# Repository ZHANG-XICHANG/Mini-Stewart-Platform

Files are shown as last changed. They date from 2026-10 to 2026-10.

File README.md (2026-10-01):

# 小型六自由度 Stewart 平台｜ESP32-C6 控制與 Python 上位機

**專案名稱：Mini-Stewart-Platform**

以 Python 上位機設定平台位置與姿態，由 ESP32-C6 計算逆運動學，再透過 PCA9685 控制六組伺服馬達。本專案涵蓋小型化機構設計、控制系統、上位機介面與實機測試。

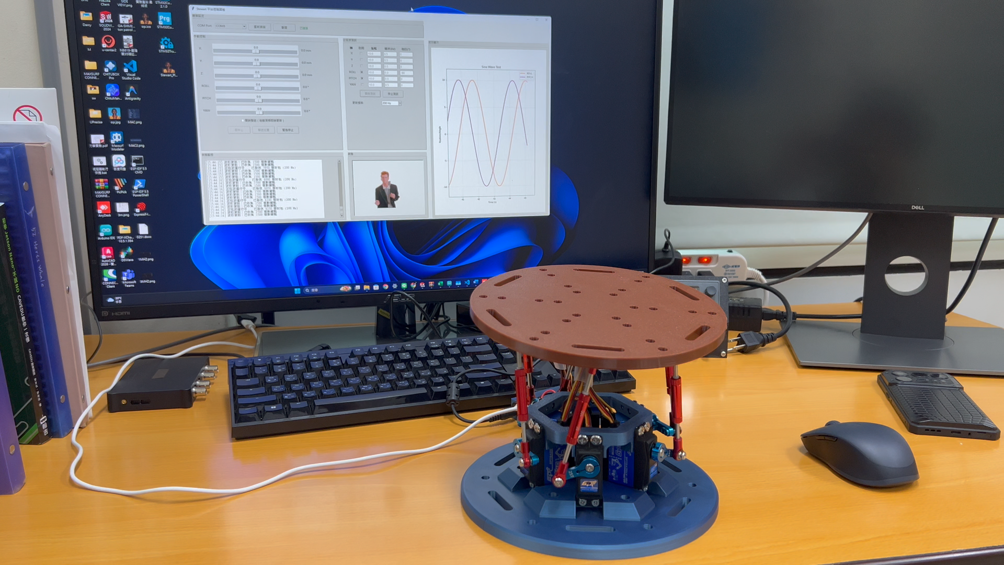
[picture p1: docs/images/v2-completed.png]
二代平台與上位機


**目前狀態：已完成實體組裝與運行測試。** 下方照片與影片展示平台實作及測試成果，本專案提供上位機程式、ESP32 韌體與機構模型，供學習與實作參考。

## 運行展示

- [二代運行影片（MP4）](docs/videos/v2-demo.mp4)
- [初代運行影片（MP4）](docs/videos/v1-demo.mp4)

影片提供 MP4 格式，可播放或下載。

## 開發歷程與個人貢獻

| 初代實機 | 二代實機 |
| --- | --- |
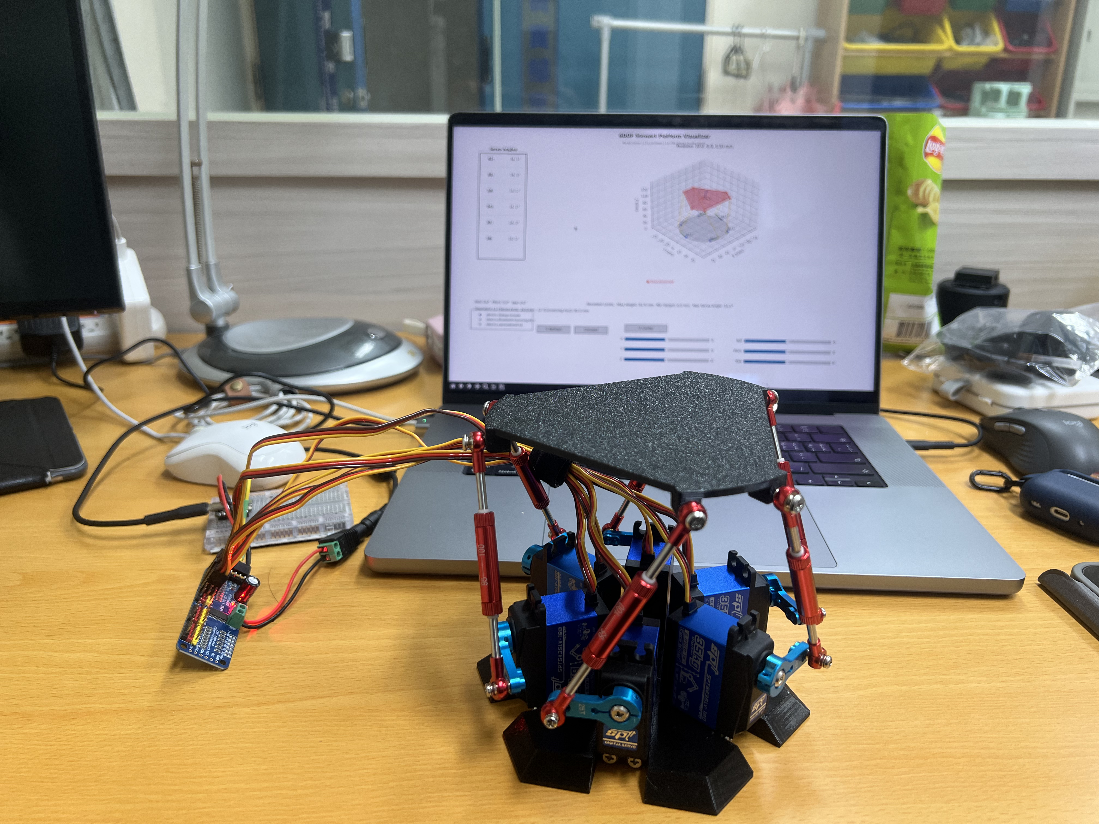
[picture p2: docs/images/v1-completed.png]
初代
|  | 二代 |

- **機構調整**：縮小平台機構，提供 STL、STEP 與 SolidWorks 設計檔。
- **控制系統**：ESP32／PCA9685 控制實作，後續版本將逆運動學移至 ESP32。
- **上位機修改**：提供六軸手動操作、各軸正弦波設定與命令波形顯示。
- **組裝與測試**：完成實體組裝及運動、負載測試；詳細測試條件與量測數據待補充。

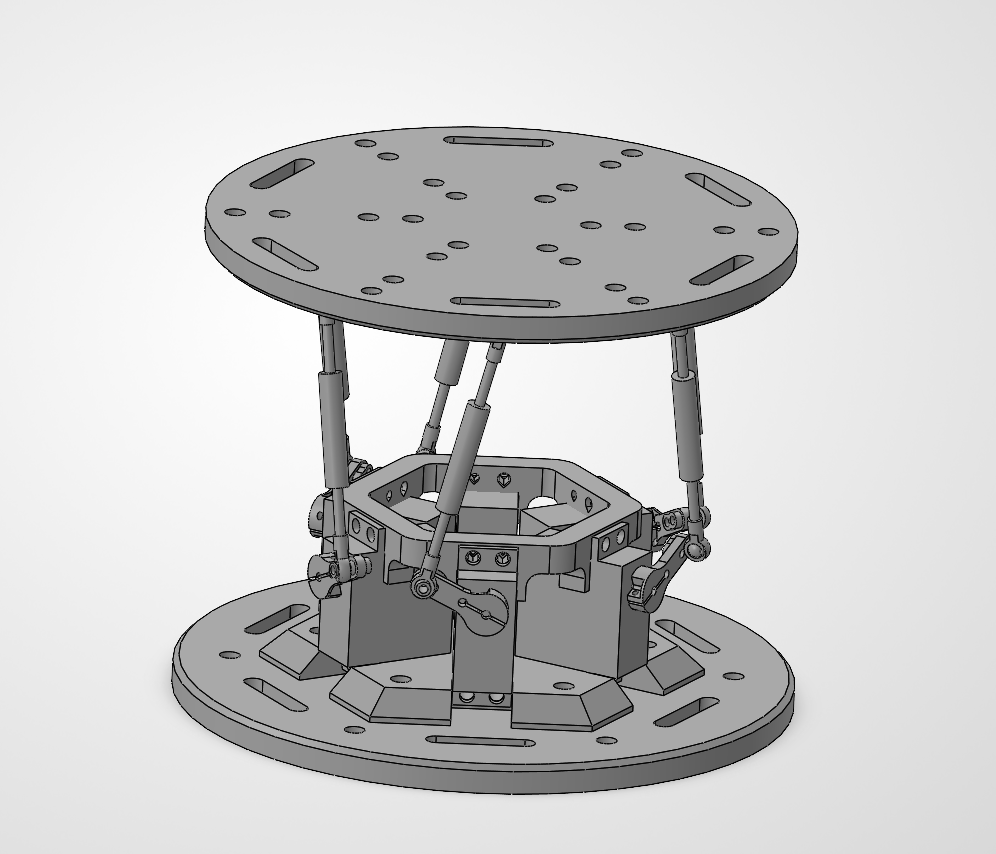
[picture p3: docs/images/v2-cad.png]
二代模型


### 負載測試紀錄

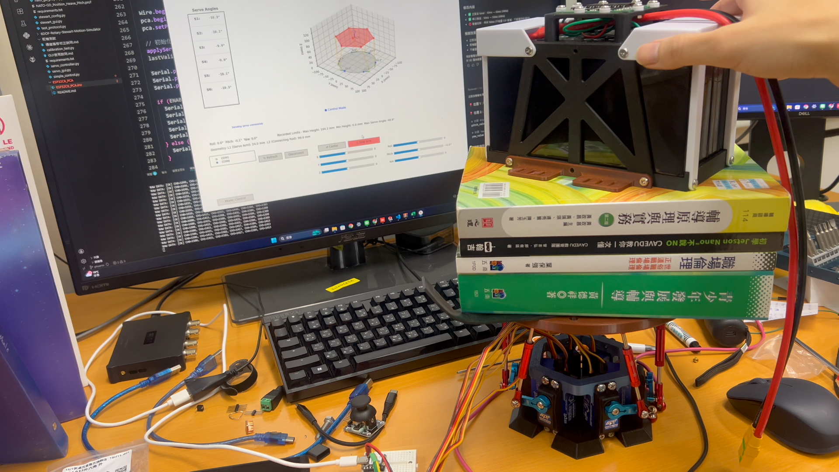
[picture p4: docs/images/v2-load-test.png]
負載測試


此照片記錄放置負載的測試情境。負載重量、持續時間、運動幅度及定位誤差尚未記錄於本專案，因此不據此宣稱最大承載量。另見 [運行照片](docs/images/v2-running.png)。

## 使用入口與目錄

本專案包含所需的上位機程式、ESP32 韌體與相依套件清單，可獨立安裝使用。

日常操作請執行根目錄的 `stewart_control_gui.py`，搭配 `firmware/ESP32C6_PCA/` 韌體。

```text
Mini-Stewart-Platform/
├── stewart_control_gui.py        # 主版本上位機
├── requirements.txt             # Python 相依套件
├── firmware/ESP32C6_PCA/
│   ├── ESP32C6_PCA.ino           # 主版本韌體
│   └── stewart_kinematics.h      # ESP32 逆運動學與幾何參數
├── GIF/Logo.gif                  # 介面標誌
├── docs/images/                  # 實機與模型照片
├── docs/videos/                  # 示範 MP4
├── models/                       # STL、STEP、SolidWorks
├── legacy/binary_pca9685/        # 舊版與二進位相容介面
├── README.md
├── LICENSE
└── .gitignore
```

主版本使用根目錄的上位機與 `firmware/`；`legacy/` 提供舊版程式作為參考。

## 主版本：上位機姿態命令 → ESP32 逆運動學

```mermaid
flowchart TD
    A[上位機：X / Y / Z / Roll / Pitch / Yaw] --> B[USB 串列：460800 baud]
    B --> C[ESP32：座標轉換與逆運動學]
    C --> D[六組馬達角度與 PWM 映射]
    D --> E[PCA9685 驅動平台]
```

| 檔案 | 用途 |
| --- | --- |
| [stewart_control_gui.py](stewart_control_gui.py) | 新版 Python 上位機，傳送姿態 |
| [ESP32C6_PCA.ino](firmware/ESP32C6_PCA/ESP32C6_PCA.ino) | 接收姿態、驅動 PCA9685 |
| [stewart_kinematics.h](firmware/ESP32C6_PCA/stewart_kinematics.h) | ESP32 端幾何參數與逆運動學；須與 ino 放在同一資料夾 |

上位機負責輸入姿態與產生測試命令；ESP32 負責逆運動學與伺服輸出。測試範圍見 [測試與驗證](docs/VALIDATION.md)。

### 安裝上位機

在專案根目錄開啟 PowerShell：

```powershell
python -m venv .venv
.\.venv\Scripts\python.exe -m pip install -r requirements.txt
.\.venv\Scripts\python.exe stewart_control_gui.py
```

需具備 Tkinter 圖形環境。`Pillow` 用於圖片；`matplotlib` 用於波形顯示；`pyserial` 用於串列通訊。`numpy` 亦供保留的舊版視覺化使用。套件版本尚未鎖定。

選擇 ESP32 的 COM 埠並連線，同一埠勿同時由 Arduino 串列監控視窗占用。`GIF/Logo.gif` 用於介面標誌；可在 `GIF/` 放入其他 GIF 作為選用動畫。缺少 GIF 時程式仍可執行。

### 燒錄與硬體設定

1. 在 Arduino IDE 安裝支援實際 ESP32-C6 開發板的 Espressif ESP32 套件。
2. 安裝 `Adafruit PWM Servo Driver Library` 及其相依套件（包含 Adafruit BusIO）。
3. 開啟 `firmware/ESP32C6_PCA/ESP32C6_PCA.ino`；同目錄必須包含 `stewart_kinematics.h`。
4. 核對下列參數與實際機構後，再編譯及上傳。

| 項目 | 主版本程式設定 |
| --- | --- |
| SDA / SCL | GPIO22 / GPIO23 |
| PCA9685 位址 / 通道 | `0x40` / CH0～CH5 |
| 串列速率 | 460800 baud |
| 伺服 PWM 頻率 | **330 Hz**，須符合實際伺服規格 |
| 姿態單位 | 平移 mm、旋轉 degree |
| 底座／平台半徑 | 68 / 68 mm |
| 搖臂／連桿長度 | 24 / 99 mm |
| 中立平台高度 | **96.04 mm** |
| 通道反轉 | CH0、CH2、CH4 |
| 通道偏移 | 80、100、100、0、100、50 µs |
| 通訊逾時 | 1 秒未收到有效姿態，觸發韌體回中位處理 |

伺服電源依規格接 PCA9685 V+，ESP32 與 PCA9685 共地。邏輯 VCC 與 I2C 上拉應配合 ESP32 的 3.3 V 邏輯。韌體包含 PCA 輸出校正，數值針對原實機，不能直接當作其他硬體的量測結果。

### 通訊配對

主版本格式（每包以換行結束）：

```text
$P,x,y,z,roll,pitch,yaw,checksum
```

上位機將數值格式化為小數兩位；checksum 為各值乘 10 後逐項截斷為整數、加總再取低 8 位。`$V,0` 關閉詳細回應、`$V,1` 開啟。韌體使用單精度浮點，上位機使用 Python 浮點，校驗在小數邊界仍需實測確認。

GUI 波形顯示的是命令值，並非感測器量測的平台實際姿態。原介面「緊急停止」的程式行為為停止測試並送出回中心命令，不是切斷馬達電源。手動送出單一命令後若未持續更新，韌體可能於 1 秒後回中位。

## 舊版與相容版

| 版本 | 上位機入口（相對專案根目錄） | 配對韌體 | 通訊格式 |
| --- | --- | --- | --- |
| 主版本 | `stewart_control_gui.py` | `firmware/ESP32C6_PCA/ESP32C6_PCA.ino` | 460800 baud、`$P` 姿態封包 |
| 舊版／相容版 | `legacy/binary_pca9685/6dof_visualizer.py` 或同目錄的 `stewart_control_gui.py` | 該目錄下的 `esp32c6_pca9685_receiver/esp32c6_pca9685_receiver.ino` | 115200 baud、12-byte 角度封包 |

兩個目錄中的上位機使用不同協定，請依表格搭配韌體。

[legacy/binary_pca9685](legacy/binary_pca9685/README.md) 提供 3D 視覺化與 PC 逆運動學相容介面，使用 **115200 baud、12-byte 角度封包**，須搭配該目錄自己的接收器。不要與主版本韌體混用。

## 3D 模型

見 [模型說明](models/README.md)：

- [STL](models/stl/)：列印零件。
- [STEP](models/step/)：組合件交換格式。
- [SolidWorks](models/solidworks/)：組合件與原生零件檔。

開啟 SolidWorks 組合件時請保留零件檔的相對位置；列印前請核對尺寸、配合間隙與材料設定。

## 測試與驗證

實機展示、軟體測試範圍及重現方式見 [測試與驗證](docs/VALIDATION.md)。使用原始碼的安裝方式請參考上方步驟。

## AI 協作說明

本專案使用 OpenAI Codex 協助文件撰寫、程式檢查與部分程式開發。

機構縮小、硬體組裝與實機測試由專案作者完成。實機照片與影片為實際成果紀錄，並非 AI 生成。AI 執行的軟體檢查不等同於硬體驗證，各項測試範圍見 [測試與驗證](docs/VALIDATION.md)。

## 來源與授權

本專案基於 [knaufinator/6DOF-Rotary-Stewart-Motion-Simulator](https://github.com/knaufinator/6DOF-Rotary-Stewart-Motion-Simulator) 進行小型化與控制系統實作，保留原有 [LICENSE](LICENSE) 與 Chris Knauf 署名。

數學推導可參考 Robert Eisele（2019）的 [Inverse Kinematics of a Stewart Platform](https://raw.org/research/inverse-kinematics-of-a-stewart-platform/)。

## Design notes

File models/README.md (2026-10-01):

# 3D 模型

| 目錄 | 內容 | 用途 |
| --- | --- | --- |
| `stl/` | 大平台、底座、控制盒、緊箍，共四個 STL | 匯入切片軟體製作零件 |
| `step/` | `組合件1.STEP` | 在支援 STEP 的 CAD 軟體檢視組合模型 |
| `solidworks/` | SLDASM 組合件與 SLDPRT 零件 | 編輯原生設計 |

開啟 `solidworks/組合件1.SLDASM` 時，請保留各零件的檔名與相對位置，以便解析組合件引用。列印前依使用的伺服、連桿與緊固件確認尺寸單位、配合間隙、列印方向及材料。

檔案格式與內容清單不代表所有 CAD 軟體或印表機皆已測試相容。

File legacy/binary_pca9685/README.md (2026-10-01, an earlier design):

# 舊版二進位控制路徑

此目錄的兩個 PC 介面都搭配 `esp32c6_pca9685_receiver/esp32c6_pca9685_receiver.ino`，使用 115200 baud、12-byte 大端序角度封包。逆運動學在電腦執行。

從此目錄啟動 `6dof_visualizer.py`（3D 視覺化）或 `stewart_control_gui.py`（二進位相容面板），一次只使用一個串列連線。先安裝根目錄的 requirements.txt。

- `stewart_kinematics.py`：從原視覺化抽出的共用計算，三個數學方法內容保持一致。
- `stewart_config.py`：舊版幾何，高度 91.92 mm。
- `pca9685_transport.py`：相容面板使用；拒絕不可達或非有限姿態，只重送最新目標，最多約 50 Hz。
- 接收器：PWM 50 Hz，SDA22／SCL23，通道 0～5，CH0、2、4 反轉。

與主版本的 460800 baud `$P` 協定、330 Hz PWM、96.04 mm 平台高度不同。相容面板尚未實機驗證。舊接收器無封包標頭或校驗碼；接收器的 DEBUG 資料不是實際姿態量測。

## 軟體測試

在本目錄執行：

```powershell
python -m unittest discover -s tests -v
```

測試使用假串列埠，不會驅動硬體。

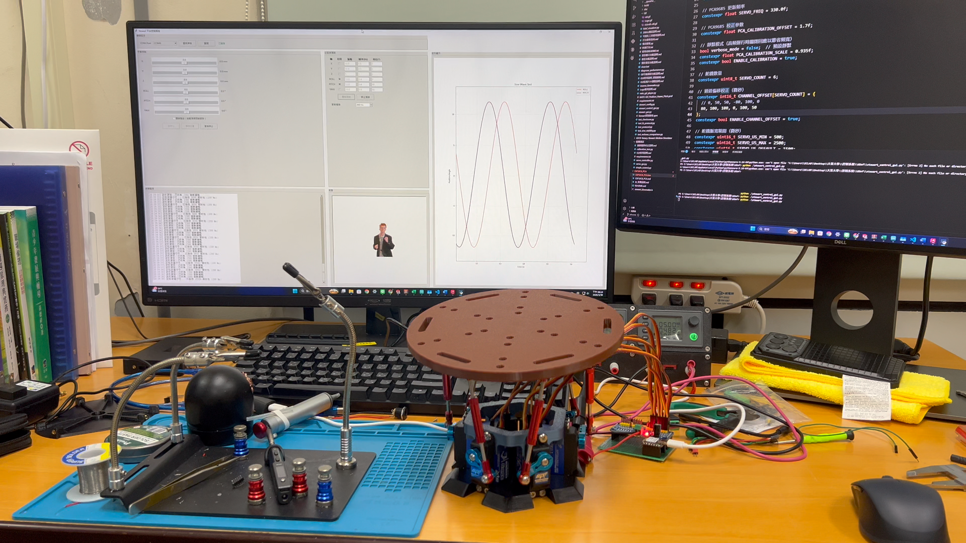
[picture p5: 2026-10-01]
docs/images/v2-running.png

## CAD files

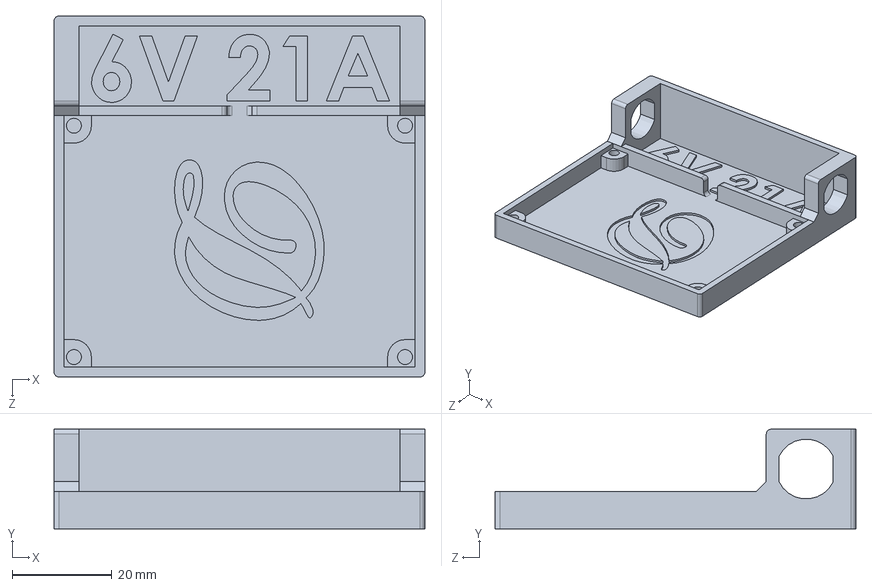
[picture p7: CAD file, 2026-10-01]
models/solidworks/控制盒.SLDPRT
74.4 x 20.0 x 72.4 mm

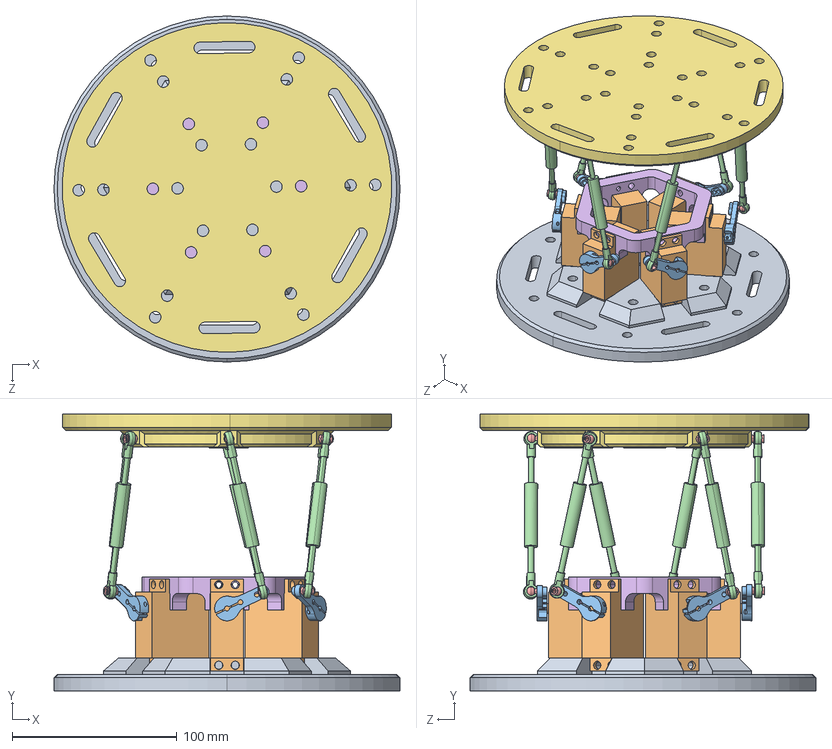
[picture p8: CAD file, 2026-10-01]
models/step/組合件1.STEP
210.0 x 168.0 x 210.0 mm
底座
舵機 x 6
搖臂 x 6
連桿 x 6
球頭 x 12
緊箍
大平台

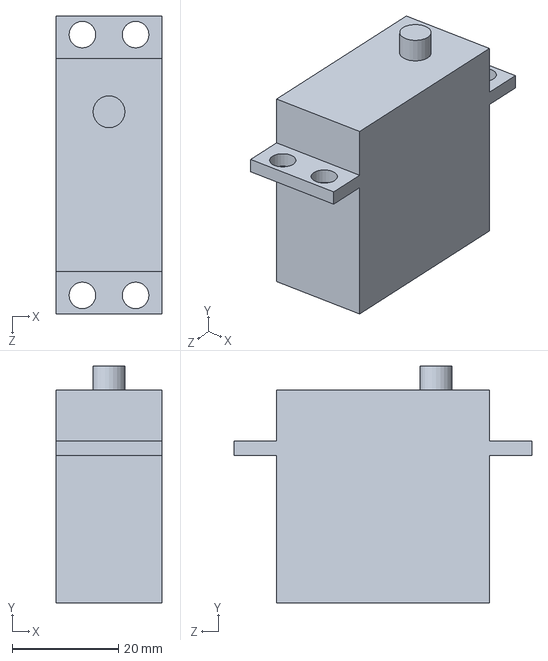
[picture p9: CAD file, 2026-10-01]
models/solidworks/舵機.SLDPRT
20.0 x 44.5 x 56.0 mm

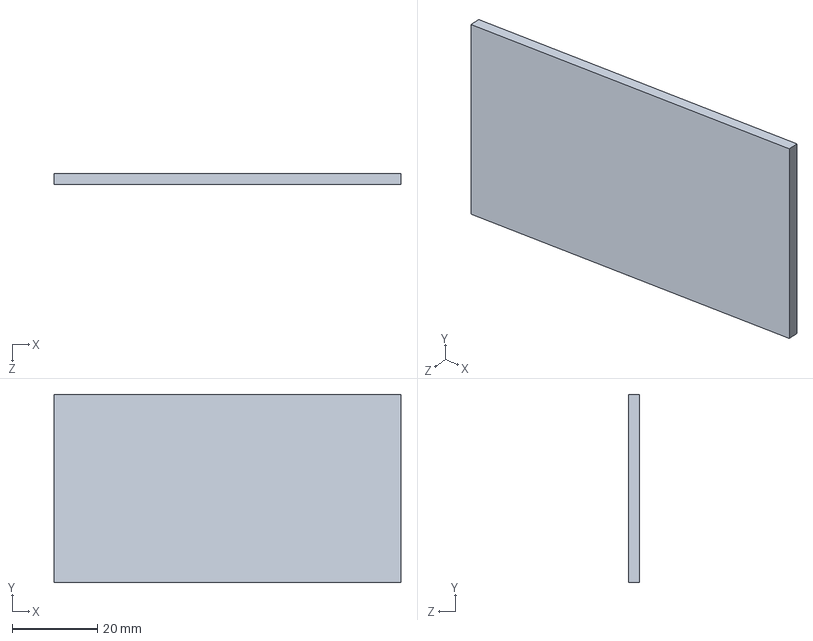
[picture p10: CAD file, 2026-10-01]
models/solidworks/零件9.SLDPRT
81.6 x 44.2 x 2.54 mm

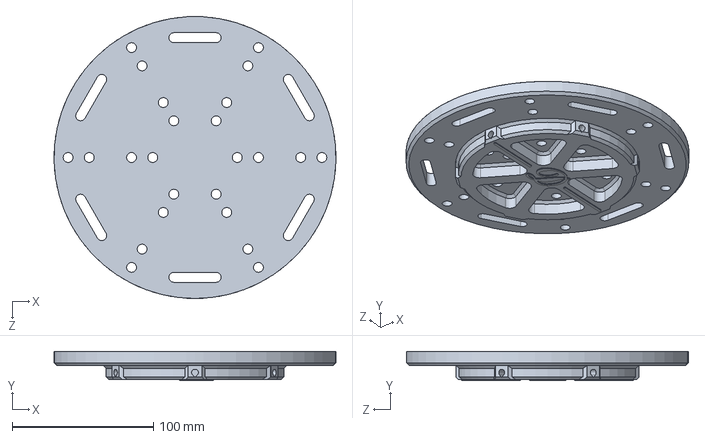
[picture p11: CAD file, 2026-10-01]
models/solidworks/大平台.SLDPRT
199.9 x 20.6 x 200.0 mm

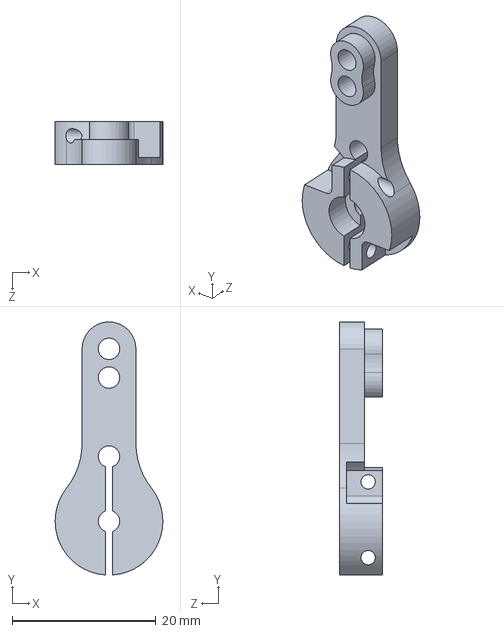
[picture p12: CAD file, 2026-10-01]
models/solidworks/搖臂.SLDPRT
15.0 x 35.2 x 6.00 mm

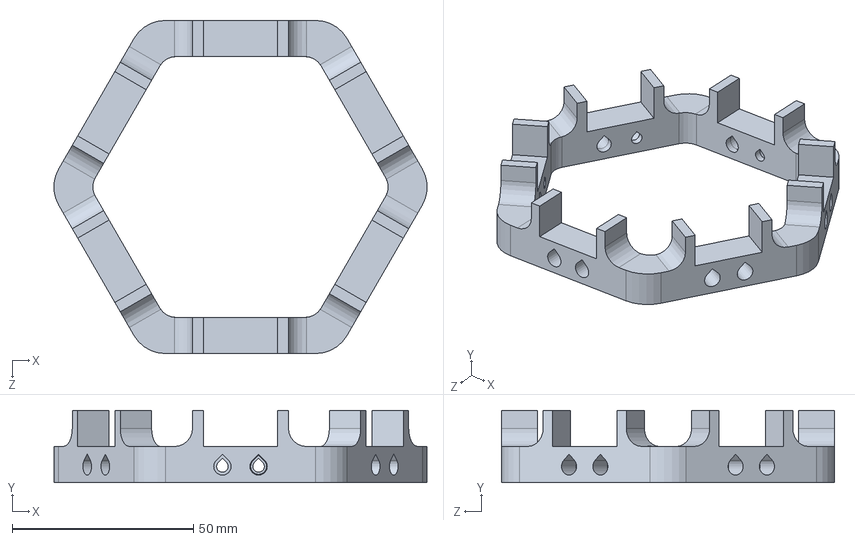
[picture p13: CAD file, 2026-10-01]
models/solidworks/緊箍.SLDPRT
103.0 x 20.0 x 92.0 mm

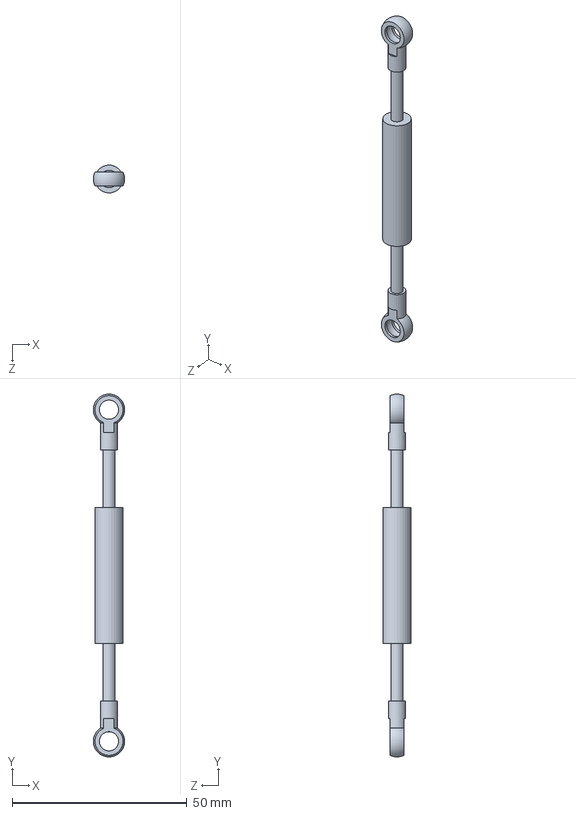
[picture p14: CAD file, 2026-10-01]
models/solidworks/連桿.SLDPRT
8.98 x 104.0 x 7.99 mm

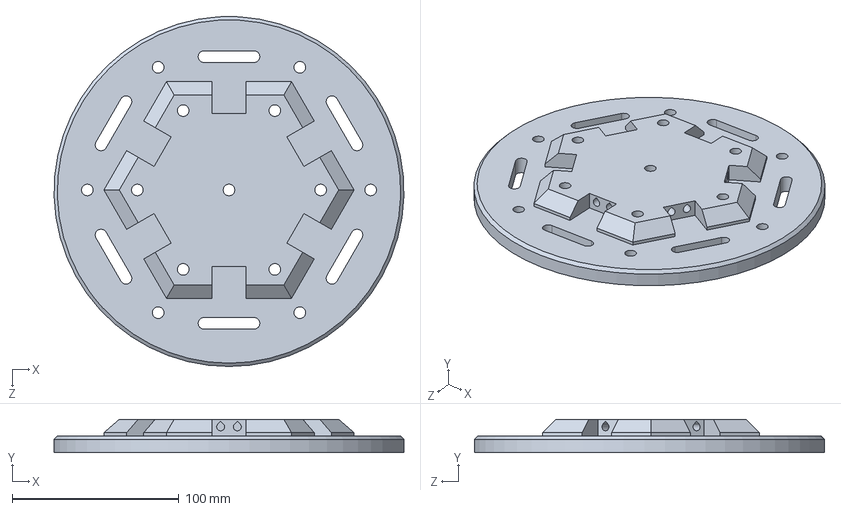
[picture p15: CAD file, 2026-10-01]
models/solidworks/底座.SLDPRT
209.9 x 20.0 x 210.0 mm

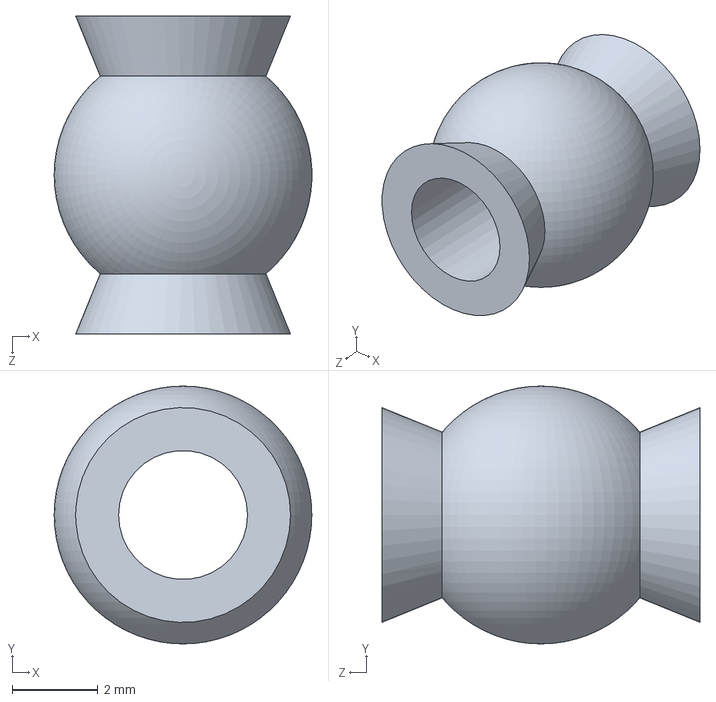
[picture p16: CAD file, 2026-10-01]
models/solidworks/球頭.SLDPRT
6.00 x 6.00 x 7.40 mm

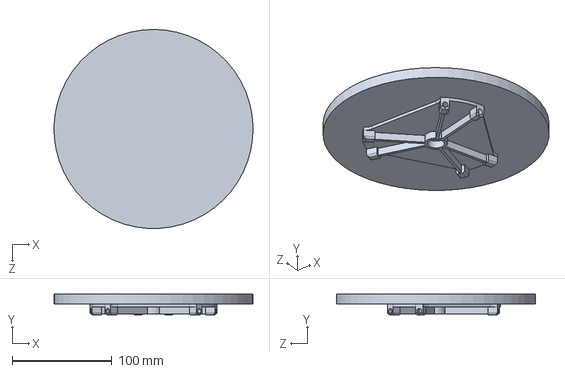
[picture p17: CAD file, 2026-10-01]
models/solidworks/平台.SLDPRT
199.9 x 21.0 x 200.0 mm

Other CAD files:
models/solidworks/組合件1.SLDASM
models/stl/大平台.STL
models/stl/底座.STL
models/stl/控制盒.STL
models/stl/緊箍.STL

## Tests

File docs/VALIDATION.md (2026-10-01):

# 測試與驗證

## 主版本實機展示

平台已完成實體組裝與運行測試，相關紀錄：

- [初代運行影片](videos/v1-demo.mp4)
- [二代運行影片](videos/v2-demo.mp4)
- [負載測試照片](images/v2-load-test.png)

上述資料展示系統運行情形；負載重量、測試時間、姿態誤差與最大工作範圍的量測數據尚未收錄，不能從展示影片推定其定量性能。

## 主版本軟體檢查

- 上位機與韌體的 460800 baud、`$P` 六軸順序、degree 旋轉單位、換行分隔及 `$V,0` 命令已經程式碼對照確認。
- 上位機的隱藏 Tk 視窗初始化檢查通過。
- 軟體檢查未包含 ESP32 編譯、燒錄及硬體串列收發測試；實機展示與軟體檢查的範圍不同。

## 舊版二進位相容面板

以下自動測試針對 `legacy/binary_pca9685`，不代表主版本韌體的測試結果：

1. 封包解碼符合接收器映射，量化誤差在一個編碼步距內。
2. 拒絕不可達姿態及 NaN／Infinity 輸入。
3. 只重送最新有效目標，並能停止傳送。
4. 串列短寫入時停止後續傳送。

四項測試均通過。測試使用假串列埠，不會驅動硬體；相容面板尚未實機驗證。

從專案根目錄進入測試目錄後執行：

```powershell
cd legacy/binary_pca9685
python -m unittest discover -s tests -v
```

共用幾何模組的三個計算方法與原視覺化方法通過 AST 比對，確認抽取時保留原計算邏輯。3D 視覺化與相容面板亦通過無硬體的初始化檢查；這些檢查不衡量機構定位精度。

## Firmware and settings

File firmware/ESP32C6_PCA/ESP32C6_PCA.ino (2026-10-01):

/**
 * ESP32-C6 + PCA9685 舵機控制器（含逆運動學）
 * 
 * 新協議：接收平台位置和姿態，自動計算舵機角度
 * 格式：$P,x,y,z,roll,pitch,yaw,checksum
 * 
 * 優點：
 * - Python 端只需發送 6 個浮點數
 * - ESP32 自主計算 IK
 * - 降低通訊負擔
 */

#include <Wire.h>
#include <Adafruit_PWMServoDriver.h>
#include "stewart_kinematics.h"

// =========================
// PCA9685 設定
// =========================
Adafruit_PWMServoDriver pca = Adafruit_PWMServoDriver(0x40);

// ESP32-C6 I2C 腳位
constexpr int I2C_SDA = 22;
constexpr int I2C_SCL = 23;

// PCA9685 更新頻率
constexpr float SERVO_FREQ = 330.0f;

// PCA9685 校正參數
constexpr float PCA_CALIBRATION_OFFSET = 1.7f;

// 靜默模式（高頻運行時關閉回應以節省頻寬）
bool verbose_mode = false;  // 預設靜默
constexpr float PCA_CALIBRATION_SCALE = 0.935f;
constexpr bool ENABLE_CALIBRATION = true;

// 舵機數量
constexpr uint8_t SERVO_COUNT = 6;

// 通道偏移校正（微秒）
constexpr int16_t CHANNEL_OFFSET[SERVO_COUNT] = {
  // 0, 50, 50, -80, 100, 0
  80, 100, 100, 0, 100, 50
};
constexpr bool ENABLE_CHANNEL_OFFSET = true;

// 舵機脈寬範圍（微秒）
constexpr uint16_t SERVO_US_MIN = 500;
constexpr uint16_t SERVO_US_MAX = 2500;
constexpr uint16_t SERVO_US_DEFAULT = 1500;

// 安全逾時
constexpr uint32_t SIGNAL_TIMEOUT_MS = 1000;

// 舵機角度反轉設定（對應 Python 的反轉）
constexpr bool INVERT_SERVO[SERVO_COUNT] = {
  true,   // S0: 反轉
  false,  // S1
  true,   // S2: 反轉
  false,  // S3
  true,   // S4: 反轉
  false   // S5
};

// =========================
// 逆運動學引擎
// =========================
StewartKinematics kinematics;

// =========================
// 序列接收緩衝
// =========================
constexpr size_t RX_BUF_SIZE = 128;
char rxBuf[RX_BUF_SIZE];
size_t rxIndex = 0;
bool frameStarted = false;
uint32_t frameStartTime = 0;
constexpr uint32_t PACKET_TIMEOUT_MS = 100;

// =========================
// 控制資料
// =========================
float current_position[3] = {0, 0, 0};      // x, y, z (mm)
float current_rotation[3] = {0, 0, 0};      // roll, pitch, yaw (度)
float servo_angles[SERVO_COUNT] = {0};      // 計算出的舵機角度（度）
uint16_t servoUs[SERVO_COUNT] = {
  SERVO_US_DEFAULT, SERVO_US_DEFAULT, SERVO_US_DEFAULT,
  SERVO_US_DEFAULT, SERVO_US_DEFAULT, SERVO_US_DEFAULT
};

uint32_t lastValidPacketTime = 0;

// =========================
// 性能監控
// =========================
uint32_t packetCount = 0;
uint32_t lastPacketTime = 0;
uint32_t packetIntervalSum = 0;
uint32_t lastStatsTime = 0;
uint32_t ikFailCount = 0;

// =========================
// 工具函式
// =========================

uint16_t clampServoUs(int value) {
  if (value < SERVO_US_MIN) return SERVO_US_MIN;
  if (value > SERVO_US_MAX) return SERVO_US_MAX;
  return (uint16_t)value;
}

uint16_t usToPcaCount(uint16_t us, float freq) {
  float period_us = 1000000.0f / freq;
  float counts = (us * 4096.0f) / period_us;
  if (counts < 0) counts = 0;
  if (counts > 4095) counts = 4095;
  return (uint16_t)(counts + 0.5f);
}

uint16_t calibrateServoUs(uint16_t targetUs) {
  if (!ENABLE_CALIBRATION) {
    return targetUs;
  }
  float calibrated = (targetUs + PCA_CALIBRATION_OFFSET) / PCA_CALIBRATION_SCALE;
  return (uint16_t)(calibrated + 0.5f);
}

void writeServoUs(uint8_t ch, uint16_t us) {
  int32_t offsetUs = us;
  if (ENABLE_CHANNEL_OFFSET && ch < SERVO_COUNT) {
    offsetUs += CHANNEL_OFFSET[ch];
    if (offsetUs < 0) offsetUs = 0;
    if (offsetUs > 4000) offsetUs = 4000;
  }
  
  uint16_t calibratedUs = calibrateServoUs((uint16_t)offsetUs);
  uint16_t offCount = usToPcaCount(calibratedUs, SERVO_FREQ);
  pca.setPWM(ch, 0, offCount);
}

// 角度轉 PWM（微秒）
uint16_t angleToPwm(float angle_deg) {
  // 限制範圍
  if (angle_deg < -60.0f) angle_deg = -60.0f;
  if (angle_deg > 60.0f) angle_deg = 60.0f;
  
  // 轉換：1500μs 為中心，±500μs 對應 ±60°
  int pwm = 1500 + (int)(angle_deg / 60.0f * 500.0f);
  return clampServoUs(pwm);
}

// 應用舵機角度（從 IK 計算結果）
void applyServoAngles() {
  for (uint8_t i = 0; i < SERVO_COUNT; i++) {
    // 應用反轉設定
    float angle = INVERT_SERVO[i] ? -servo_angles[i] : servo_angles[i];
    servoUs[i] = angleToPwm(angle);
    writeServoUs(i, servoUs[i]);
  }
}

// 解析平台姿態封包
// 格式：$P,x,y,z,roll,pitch,yaw,CS
bool parsePositionPacket(char *packet) {
  if (packet[0] != '$') return false;

  char *token = strtok(packet, ",");
  if (token == nullptr || strcmp(token, "$P") != 0) return false;

  // 解析 6 個浮點數
  float values[6];
  for (uint8_t i = 0; i < 6; i++) {
    token = strtok(nullptr, ",");
    if (token == nullptr) return false;
    values[i] = atof(token);
  }

  // Checksum（簡單累加）
  token = strtok(nullptr, ",");
  if (token == nullptr) return false;
  int receivedCS = atoi(token);
  
  // 計算 checksum（浮點數的簡單 hash）
  int calculatedCS = 0;
  for (uint8_t i = 0; i < 6; i++) {
    calculatedCS += (int)(values[i] * 10);  // 放大 10 倍後取整
  }
  calculatedCS = calculatedCS & 0xFF;

  if (receivedCS != calculatedCS) {
    Serial.print("[ERR] Checksum mismatch, recv=");
    Serial.print(receivedCS);
    Serial.print(" calc=");
    Serial.println(calculatedCS);
    return false;
  }

  // 更新當前位置和旋轉
  current_position[0] = values[0];  // x
  current_position[1] = values[1];  // y
  current_position[2] = values[2];  // z
  current_rotation[0] = values[3];  // roll
  current_rotation[1] = values[4];  // pitch
  current_rotation[2] = values[5];  // yaw

  // **計算逆運動學**
  bool ik_success = kinematics.calculateServoAngles(
    current_position,
    current_rotation,
    servo_angles
  );

  if (!ik_success) {
    ikFailCount++;
    Serial.println("[WARN] IK calculation failed (out of limits)");
    return false;
  }

  uint32_t now = millis();
  lastValidPacketTime = now;
  
  // 性能監控
  if (lastPacketTime > 0) {
    uint32_t interval = now - lastPacketTime;
    packetIntervalSum += interval;
    packetCount++;
  }
  lastPacketTime = now;
  
  return true;
}

void serviceSerial() {
  if (frameStarted && (millis() - frameStartTime) > PACKET_TIMEOUT_MS) {
    Serial.println("[WARN] Packet timeout, resetting buffer");
    frameStarted = false;
    rxIndex = 0;
  }
  
  uint8_t processedChars = 0;
  constexpr uint8_t MAX_CHARS_PER_LOOP = 128;
  
  while (Serial.available() > 0 && processedChars < MAX_CHARS_PER_LOOP) {
    char c = (char)Serial.read();
    processedChars++;

    if (!frameStarted) {
      if (c == '$') {
        frameStarted = true;
        rxIndex = 0;
        rxBuf[rxIndex++] = c;
        frameStartTime = millis();
      }
      continue;
    }

    if (c == '\n' || c == '\r') {
      if (rxIndex > 0) {
        rxBuf[rxIndex] = '\0';

        char parseBuf[RX_BUF_SIZE];
        strncpy(parseBuf, rxBuf, RX_BUF_SIZE);
        parseBuf[RX_BUF_SIZE - 1] = '\0';

        // 檢查 Verbose 模式切換命令：$V,0 或 $V,1
        if (strncmp(parseBuf, "$V,", 3) == 0) {
          int mode = atoi(parseBuf + 3);
          verbose_mode = (mode != 0);
          Serial.print("[CONFIG] Verbose mode: ");
          Serial.println(verbose_mode ? "ON" : "OFF");
        }
        else if (parsePositionPacket(parseBuf)) {
          applyServoAngles();

          // 只在 verbose 模式下回應（節省頻寬）
          if (verbose_mode) {
            Serial.print("[OK] Pos:(");
            Serial.print(current_position[0], 1);
            Serial.print(",");
            Serial.print(current_position[1], 1);
            Serial.print(",");
            Serial.print(current_position[2], 1);
            Serial.print(") Rot:(");
            Serial.print(current_rotation[0], 1);
            Serial.print(",");
            Serial.print(current_rotation[1], 1);
            Serial.print(",");
            Serial.print(current_rotation[2], 1);
            Serial.print(") -> Angles:");
            for (uint8_t i = 0; i < SERVO_COUNT; i++) {
              Serial.print(servo_angles[i], 1);
              if (i < SERVO_COUNT - 1) Serial.print(",");
            }
            Serial.println();
          }
        }
      }

      frameStarted = false;
      rxIndex = 0;
      continue;
    }

    if (rxIndex < RX_BUF_SIZE - 1) {
      rxBuf[rxIndex++] = c;
    } else {
      frameStarted = false;
      rxIndex = 0;
      Serial.println("[ERR] RX buffer overflow");
    }
  }
}

void serviceFailsafe() {
  static bool failsafeActive = false;
  uint32_t now = millis();

  if ((now - lastValidPacketTime) > SIGNAL_TIMEOUT_MS) {
    if (!failsafeActive) {
      // 回到中位
      for (uint8_t i = 0; i < SERVO_COUNT; i++) {
        servo_angles[i] = 0;
        servoUs[i] = SERVO_US_DEFAULT;
      }
      applyServoAngles();
      failsafeActive = true;
      Serial.println("[WARN] Signal timeout -> servos back to neutral");
    }
  } else {
    failsafeActive = false;
  }
}

void setup() {
  Serial.begin(460800);

  Wire.begin(I2C_SDA, I2C_SCL);
  Wire.setClock(400000);  // I2C Fast Mode: 400kHz
  pca.begin();
  pca.setPWMFreq(SERVO_FREQ);

  // 初始化到中位
  applyServoAngles();
  lastValidPacketTime = millis();

  Serial.println("ESP32-C6 Stewart Platform Controller (with IK)");
  Serial.println("Format: $P,x,y,z,roll,pitch,yaw,CS");
  Serial.println("  Position: x,y,z in mm");
  Serial.println("  Rotation: roll,pitch,yaw in degrees");
  Serial.println("  Checksum: sum(values*10) & 0xFF");
  
  if (ENABLE_CALIBRATION) {
    Serial.print("PCA Calibration: ENABLED (offset=");
    Serial.print(PCA_CALIBRATION_OFFSET);
    Serial.print(", scale=");
    Serial.print(PCA_CALIBRATION_SCALE);
    Serial.println(")");
  }
  
  Serial.println("IK Engine: READY");
}

void loop() {
  serviceSerial();
  serviceFailsafe();
  
  // 性能統計
  uint32_t now = millis();
  if (now - lastStatsTime > 5000 && packetCount > 0) {
    float avgInterval = (float)packetIntervalSum / packetCount;
    float actualHz = 1000.0f / avgInterval;
    
    Serial.print("[ESP32-PERF] Packets: ");
    Serial.print(packetCount);
    Serial.print(", Avg: ");
    Serial.print(avgInterval, 1);
    Serial.print("ms (");
    Serial.print(actualHz, 1);
    Serial.print("Hz), IK fails: ");
    Serial.println(ikFailCount);
    
    packetCount = 0;
    packetIntervalSum = 0;
    ikFailCount = 0;
    lastStatsTime = now;
  }
  
  // 定期清理緩衝區
  static uint32_t lastFlushTime = 0;
  if ((millis() - lastFlushTime) > 1000) {
    if (!frameStarted && Serial.available() > 50) {
      while (Serial.available() > 0) Serial.read();
      Serial.println("[INFO] Flushed stale serial data");
    }
    lastFlushTime = millis();
  }
}

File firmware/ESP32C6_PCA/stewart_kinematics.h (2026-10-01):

/**
 * Stewart Platform Inverse Kinematics
 * 
 * 從 Python 版本移植的逆運動學計算
 * 輸入：平台位置 (x,y,z) 和姿態 (roll,pitch,yaw)
 * 輸出：6 個舵機角度（度）
 */

#ifndef STEWART_KINEMATICS_H
#define STEWART_KINEMATICS_H

#include <math.h>

// =========================
// 平台幾何參數（與 stewart_config.py 一致）
// =========================
namespace StewartConfig {
  // 半徑（mm）
  constexpr float BASE_RADIUS = 68.0f;
  constexpr float PLATFORM_RADIUS = 68.0f;
  
  // 臂長（mm）
  constexpr float SERVO_ARM_LENGTH = 24.0f;     // L1
  constexpr float CONNECTING_ARM_LENGTH = 99.0f; // L2
  
  // 平台高度（mm）
  constexpr float PLATFORM_HEIGHT = 96.04f;

  
  // 角度參數（度）
  constexpr float THETA_R = 30.0f;
  constexpr float THETA_P = 30.0f;
  
  // 舵機角度（度）
  const float THETA_S[6] = {150, -90, 30, 150, -90, 30};
  
  // 角度限制（度）
  constexpr float SERVO_MIN_ANGLE = -60.0f;
  constexpr float SERVO_MAX_ANGLE = 60.0f;
  
  // 幾何係數（從 Python 移植）
  const int DX_MULTIPLIER[6] = {1, 1, 1, -1, -1, -1};
  const int ANGLE_MULTIPLIER[6] = {1, -1, 1, 1, -1, 1};
  
  // 偏移角度（弧度）
  const float OFFSET_ANGLE[6] = {
    M_PI/6,    // 30 degrees
    M_PI/6,    // 30 degrees
    -M_PI/2,   // -90 degrees
    -M_PI/2,   // -90 degrees
    M_PI/6,    // 30 degrees
    M_PI/6     // 30 degrees
  };
}

// =========================
// 逆運動學計算類別
// =========================
class StewartKinematics {
private:
  // 平台和基座坐標（預先計算）
  float platform_coords_x[6];
  float platform_coords_y[6];
  float base_coords_x[6];
  float base_coords_y[6];
  
  // 角度轉換
  inline float deg2rad(float deg) { return deg * M_PI / 180.0f; }
  inline float rad2deg(float rad) { return rad * 180.0f / M_PI; }

public:
  StewartKinematics() {
    calculateGeometry();
  }
  
  // 計算平台幾何（建構時執行一次）
  void calculateGeometry() {
    using namespace StewartConfig;
    
    for (int i = 0; i < 6; i++) {
      // 平台坐標
      float platform_pd_x = DX_MULTIPLIER[i] * BASE_RADIUS;
      float platform_pd_y = BASE_RADIUS;
      float platform_angle = OFFSET_ANGLE[i] + ANGLE_MULTIPLIER[i] * deg2rad(THETA_R);
      platform_coords_x[i] = platform_pd_x * cos(platform_angle);
      platform_coords_y[i] = platform_pd_y * sin(platform_angle);
      
      // 基座坐標
      float base_pd_x = DX_MULTIPLIER[i] * PLATFORM_RADIUS;
      float base_pd_y = PLATFORM_RADIUS;
      float base_angle = OFFSET_ANGLE[i] + ANGLE_MULTIPLIER[i] * deg2rad(THETA_P);
      base_coords_x[i] = base_pd_x * cos(base_angle);
      base_coords_y[i] = base_pd_y * sin(base_angle);
    }
  }
  
  /**
   * 計算舵機角度
   * 
   * @param position 位置 [x, y, z] (mm)
   * @param rotation 旋轉 [roll, pitch, yaw] (度)
   * @param servo_angles 輸出：舵機角度陣列 (度)
   * @return true 如果成功，false 如果超出限制
   */
  bool calculateServoAngles(
    const float position[3],
    const float rotation[3],
    float servo_angles[6]
  ) {
    using namespace StewartConfig;
    
    // 轉換旋轉角度為弧度
    float roll = deg2rad(rotation[0]);
    float pitch = deg2rad(rotation[1]);
    float yaw = deg2rad(rotation[2]);
    
    // 預先計算三角函數
    float cos_roll = cos(roll);
    float sin_roll = sin(roll);
    float cos_pitch = cos(pitch);
    float sin_pitch = sin(pitch);
    float cos_yaw = cos(yaw);
    float sin_yaw = sin(yaw);
    
    // 計算每個舵機的角度
    for (int i = 0; i < 6; i++) {
      // 變換平台坐標（基於位置和旋轉）
      float platform_pivot_x = 
        platform_coords_x[i] * cos_roll * cos_yaw + 
        platform_coords_y[i] * (sin_pitch * sin_roll * cos_yaw - cos_pitch * sin_yaw) + 
        position[0];
      
      float platform_pivot_y = 
        platform_coords_x[i] * cos_pitch * sin_yaw + 
        platform_coords_y[i] * (cos_roll * cos_yaw + sin_roll * sin_pitch * sin_yaw) + 
        position[1];
      
      float platform_pivot_z = 
        -platform_coords_x[i] * sin_roll + 
        platform_coords_y[i] * sin_pitch * cos_roll + 
        PLATFORM_HEIGHT + position[2];
      
      // 計算腿向量
      float delta_Lx = base_coords_x[i] - platform_pivot_x;
      float delta_Ly = base_coords_y[i] - platform_pivot_y;
      float delta_Lz = -platform_pivot_z;
      
      // 計算虛擬腿長
      float delta_L2_virtual = sqrt(
        delta_Lx * delta_Lx + 
        delta_Ly * delta_Ly + 
        delta_Lz * delta_Lz
      );
      
      // 檢查連接桿長度限制
      if (fabs(delta_L2_virtual - SERVO_ARM_LENGTH) > CONNECTING_ARM_LENGTH) {
        return false;  // 超出連接桿長度
      }
      
      // 計算中間值
      float l = delta_L2_virtual * delta_L2_virtual - 
                (CONNECTING_ARM_LENGTH * CONNECTING_ARM_LENGTH - 
                 SERVO_ARM_LENGTH * SERVO_ARM_LENGTH);
      float m = 2 * SERVO_ARM_LENGTH * platform_pivot_z;
      
      float theta_s_rad = deg2rad(THETA_S[i]);
      float n = 2 * SERVO_ARM_LENGTH * 
                (cos(theta_s_rad) * (platform_pivot_x - base_coords_x[i]) + 
                 sin(theta_s_rad) * (platform_pivot_y - base_coords_y[i]));
      
      // 檢查數學有效性
      float discriminant = m * m + n * n;
      if (discriminant <= 0) {
        return false;  // 無有效解
      }
      
      float check_val = l / sqrt(discriminant);
      if (fabs(check_val) > 1.0f) {
        return false;  // asin 定義域錯誤
      }
      
      // 計算舵機角度（弧度）
      float alpha = asin(check_val) - atan2(n, m);
      
      // 轉換為度並檢查範圍
      float alpha_deg = rad2deg(alpha);
      if (alpha_deg < SERVO_MIN_ANGLE || alpha_deg > SERVO_MAX_ANGLE) {
        return false;  // 超出舵機角度限制
      }
      
      servo_angles[i] = alpha_deg;
    }
    
    return true;  // 計算成功
  }
};

#endif // STEWART_KINEMATICS_H

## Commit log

2026-10-01 Initial release of Mini Stewart Platform
    [大平台.SLDPRT, 大平台.STL, 平台.SLDPRT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]
2026-10-29 Add GitHub Pages showcase site under docs/
    - Add docs/index.html: Traditional Chinese, dark, responsive project site
    (mechanism, inverse kinematics, control architecture, results,
    challenges, future work)
    - Add interactive 6-DOF simulation ported line-by-line from
    firmware/ESP32C6_PCA/stewart_kinematics.h (clearly labeled as simulation)
    - Add Archify interactive diagrams and PowerPoint-ready architecture
    diagrams (PNG/SVG, dark and light)
    - Add web-optimized photos; missing measurements marked as pending
    - Add .nojekyll for GitHub Pages
2026-10-29 Fix swapped cos(roll)/cos(pitch) in rotation matrix row 2
    The inherited expansion used cos(pitch)*sin(yaw) and cos(roll)*cos(yaw)
    in platform_pivot_y, so R was not orthogonal (platform stretched under
    pitch, compressed under roll). Use standard Rz(yaw)*Ry(roll)*Rx(pitch)
    in firmware and the legacy Python solver. Servo-angle change is about
    0.3 deg at 10 deg single-axis tilt; neutral, translation and pure yaw
    are unaffected. Update the site and VALIDATION.md accordingly.
2026-10-29 Add English README as default, move Chinese to README.zh-TW.md
    - README.md is now the English version shown on the GitHub homepage
    - Traditional Chinese version moved to README.zh-TW.md
    - Language switch links at the top of both files
2026-10-30 Add Marp technical presentation and link it from README and site
    - presentations/: 15-slide Marp deck (zh-TW, 16:9 dark theme) with
    exported PDF and PPTX, theme CSS, photos, Archify diagrams, and
    figures.py that regenerates the geometry/simulation charts from the
    firmware inverse kinematics
    - docs/slides/: HTML build of the deck for GitHub Pages
    - README (en, zh-TW) and docs/index.html link to the slides
